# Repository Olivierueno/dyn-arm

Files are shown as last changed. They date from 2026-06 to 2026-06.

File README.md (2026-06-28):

# dyn-arm

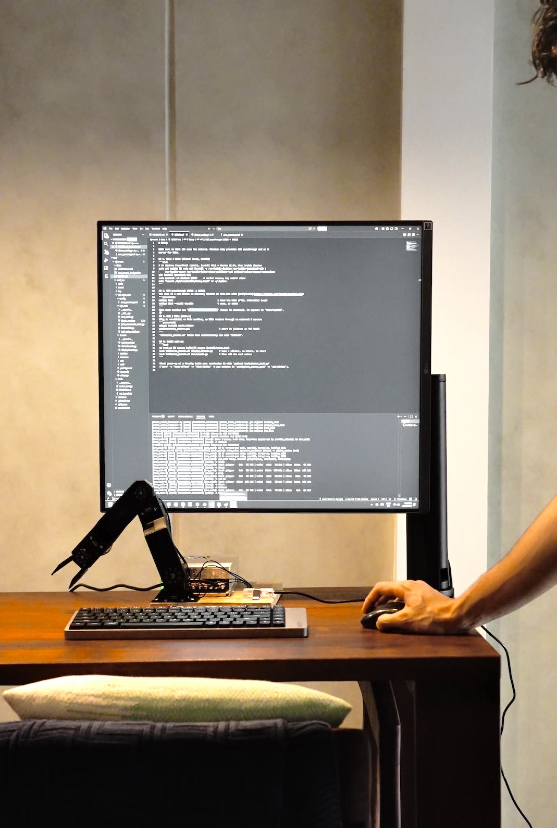
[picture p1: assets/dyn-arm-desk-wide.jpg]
dyn-arm on a desk


A 3-DOF ROS2 robotic arm using Dynamixel servos, 3D-printed structure, a U2D2
USB serial converter, and an RViz digital twin.

## What is included

- ROS2 Humble package for the arm driver, RViz model, and demo.
- STL files in `ros2_ws/src/dyn_arm/meshes/`.
- Motor setup tools in `tools/motor_tool.py`.
- Windows/WSL helpers for U2D2 passthrough and RViz display.
- Safety layers: joint limits, firmware limits, virtual floor, torque caps, and
  watchdog home fallback.

## Hardware

| Qty | Part |
| --- | --- |
| 2 | Dynamixel XM430-W210-R |
| 1 | Dynamixel XM540-W270-R |
| 1 | U2D2 USB serial converter |
| 1 | USB-C cable |
| 1 | 12 V 30 A power supply |
| 1 | Wooden platform |
| 1 | 3D printer |
| 8 | M3 x 10 mm bolts |
| 16 | M3 x 6 mm bolts |
| 8 | M2.5 x 10 mm bolts |
| 8 | M2.5 x 8 mm bolts |

Printed parts are in `ros2_ws/src/dyn_arm/meshes/`. PLA at 50% infill worked
for this build.

## Setup

Install ROS2 Humble on Ubuntu 22.04, then install the project dependencies:

```bash
sudo apt update
sudo apt install -y \
  ros-humble-desktop \
  ros-humble-dynamixel-sdk \
  ros-humble-xacro \
  ros-humble-joint-state-publisher-gui \
  python3-colcon-common-extensions

pip install dynamixel-sdk
sudo usermod -aG dialout $USER
```

Build the workspace:

```bash
cd ros2_ws
colcon build
source install/setup.bash
cd ..
```

For WSL2 USB/RViz notes and first motor setup, see [docs/SETUP.md](docs/SETUP.md).

## Commissioning

With the U2D2 attached as `/dev/ttyUSB0` and the 12 V motor supply on:

```bash
python3 tools/motor_tool.py scan
python3 tools/motor_tool.py zero
python3 tools/motor_tool.py find-limits
```

Copy the measured joint limits into
`ros2_ws/src/dyn_arm/config/arm_params.yaml`, then write them to the motors:

```bash
python3 tools/motor_tool.py set-limits
```

The config arrays are ordered `[gripper, wrist, elbow]`.

## Run

Digital twin only:

```bash
bash tools/ros_launch.sh display.launch.py
```

Real arm with RViz sliders:

```bash
bash tools/ros_launch.sh arm.launch.py
```

Scripted demo:

```bash
bash tools/ros_launch.sh demo.launch.py
```

## More photos

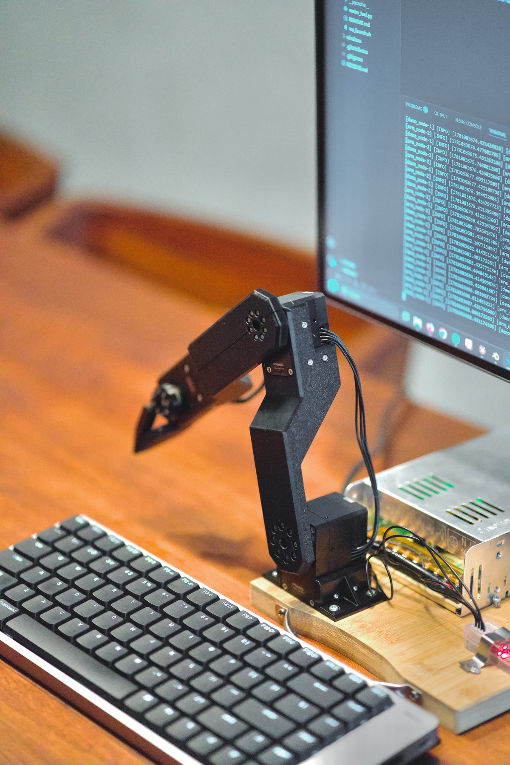
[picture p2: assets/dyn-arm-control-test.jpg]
dyn-arm closeup


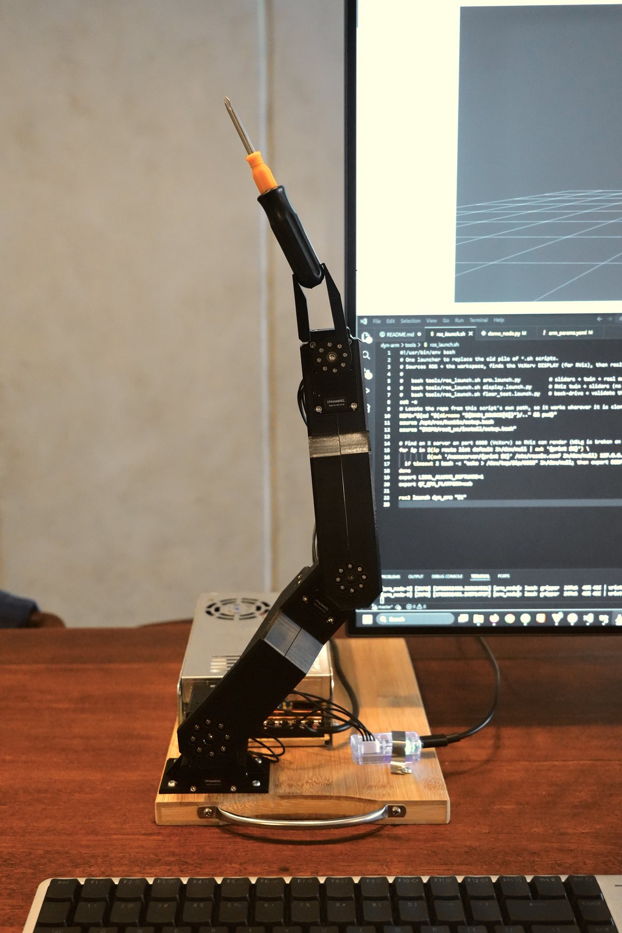
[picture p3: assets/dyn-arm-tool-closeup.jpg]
dyn-arm tool pose


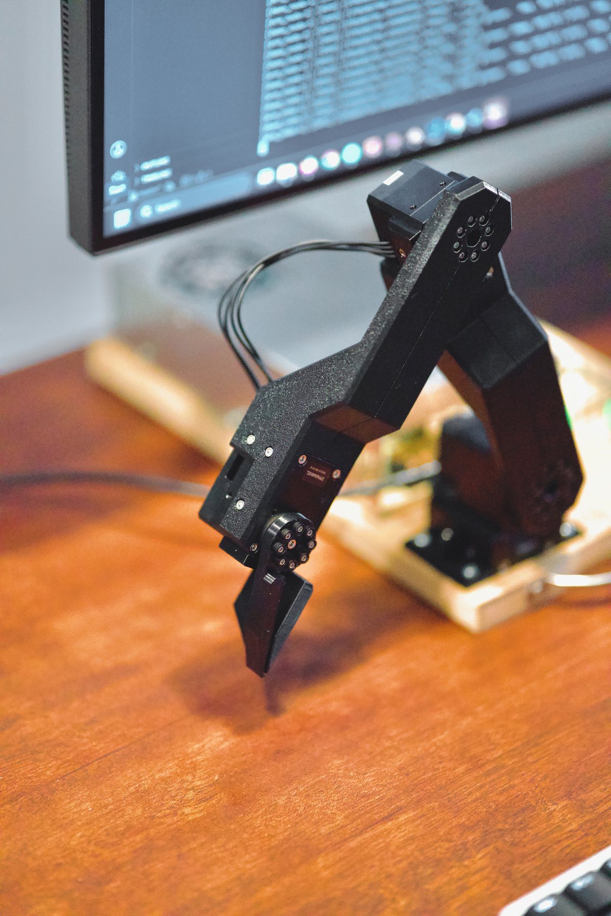
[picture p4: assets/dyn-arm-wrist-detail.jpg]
dyn-arm wrist detail


## Docs

- [Setup guide](docs/SETUP.md)
- [Architecture notes](docs/architecture.md)
- [Torque budget](docs/arm_torque_budget.xlsx)
- [Motor tool reference](tools/README.md)

## License

MIT. See [LICENSE](LICENSE).

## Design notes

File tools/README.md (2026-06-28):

# Tools

Two helpers, both run in WSL.

### `motor_tool.py` - direct-to-motor utilities (not a ROS node)
One CLI for every low-level motor task. U2D2 attached, 12 V on:
```bash
python3 tools/motor_tool.py scan                 # find motors across baud rates
python3 tools/motor_tool.py read                 # pos / goal / torque / error per motor
python3 tools/motor_tool.py zero                 # center all motors (2048) and hold, for assembly
python3 tools/motor_tool.py home-offset 1 2048   # calibrate a joint zero in firmware
python3 tools/motor_tool.py find-limits          # back-drive by hand, capture min/max ticks
python3 tools/motor_tool.py teach                # pose the arm by hand, record demo poses
python3 tools/motor_tool.py set-limits           # burn config lo/hi into motor EEPROM
```
Commissioning order: `zero` -> `home-offset` (if a horn is clocked off) -> `find-limits` ->
copy the numbers into `ros2_ws/src/dyn_arm/config/arm_params.yaml` -> `set-limits`.

### `ros_launch.sh` - the ROS2 launcher
Sources the workspace and sets the RViz display, then launches:
```bash
bash tools/ros_launch.sh arm.launch.py          # sliders + twin + real motors
bash tools/ros_launch.sh demo.launch.py         # hands-free choreography; twin follows
bash tools/ros_launch.sh display.launch.py      # RViz twin only (no motors)
```

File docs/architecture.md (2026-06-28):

# Design notes

## Commanding the arm

Joint targets come from the standard `joint_state_publisher_gui` (one slider per joint),
which publishes `/joint_states` in radians. Two consumers read it:

- `robot_state_publisher` turns it into TF and the RViz **twin**.
- `joint_command_node` converts radians to motor **ticks** and publishes `/goal_positions`,
  which `arm_node` drives the motors from.

So the twin and the real arm are driven from the same source and always agree.
(This project began as a webcam mimic; that input was removed to keep it focused, and it is
recoverable from git history if ever wanted.)

## Coordinates and calibration

Everything is in raw Dynamixel ticks (4096 ticks = one revolution) until the last moment.
`2048` is defined as the **straight-up** pose, where every joint angle is zero. The per-joint
tick<->radian mapping (`CALIB` in `kinematics.py`) is the single place that conversion lives,
used both to drive the motors (radians->ticks) and to draw the twin (ticks->radians).

One servo horn was bolted on ~65 deg off true. Rather than fight the spline, it was corrected
in firmware with the **Homing Offset** register (control-table address 20): the motor adds a
fixed offset to every reported position, so the physical neutral reads as 2048 to all
software above it. It is the digital equivalent of taring a load cell.

## The virtual floor (forward kinematics)

Per-joint limits are a box in joint space; "the gripper must not hit the table" is a diagonal
constraint that couples the elbow and wrist. We compute the gripper-tip height directly:

```
tip_height = elbow_axis_height + L1*cos(elbow) + L2*cos(elbow + wrist)
```

- Angles are measured **from vertical**, so vertical height uses `cos` (a link tilted by
  theta from vertical contributes `L*cos(theta)`). At straight up both cosines are 1, giving
  the maximum tip height (~377 mm); any bend lowers it.
- Both joint signs are **+**, so bending the elbow and wrist the same physical way **adds**
  in `(elbow + wrist)`, matching the real linkage. (A wrong sign here cancels the two angles
  and silently over-estimates the height, a bug found and fixed during bring-up.)

`arm_node` rejects any goal whose predicted tip height is below `floor_margin`, holding the
last safe pose instead. The formula was validated against a tape measure during bring-up by
back-driving the arm (torque off) and comparing the predicted tip height to reality.

## Why current-based holding, not "cut torque on overcurrent"

A tempting failsafe is to watch motor current and disable torque on a spike. That is wrong
for a vertical arm: cutting torque drops it **into** the obstacle. Instead the motors run in
current-based position control (operating mode 5) with a per-joint torque cap, so contact is
a soft current-limited stall that still holds the arm up. This is foldback current limiting,
not an emergency stop.

## Motion smoothing

Motion stays calm via a command **deadband** in the driver (ignore sub-degree goal wobble),
the Dynamixel **profile acceleration/velocity** (trapezoidal ramps instead of instant jerk),
and per-joint **P/D gains**. The light gripper in particular needed high damping (D) and low
stiffness (P) to stop it hunting and chattering at idle.

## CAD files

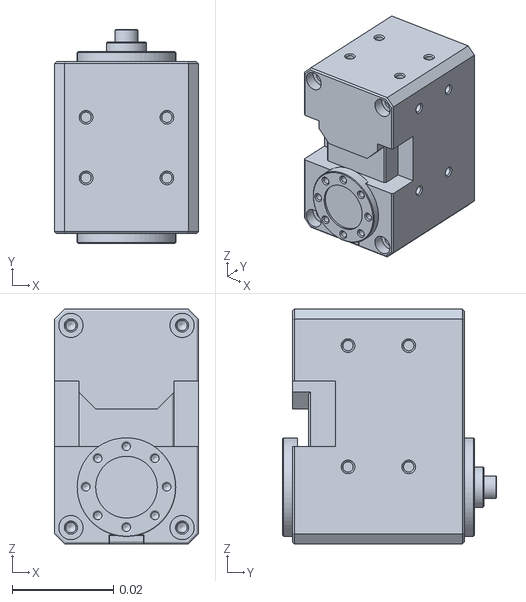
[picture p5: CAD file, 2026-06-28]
ros2_ws/src/dyn_arm/meshes/xm430.stl
0.0285 x 0.0424 x 0.0465

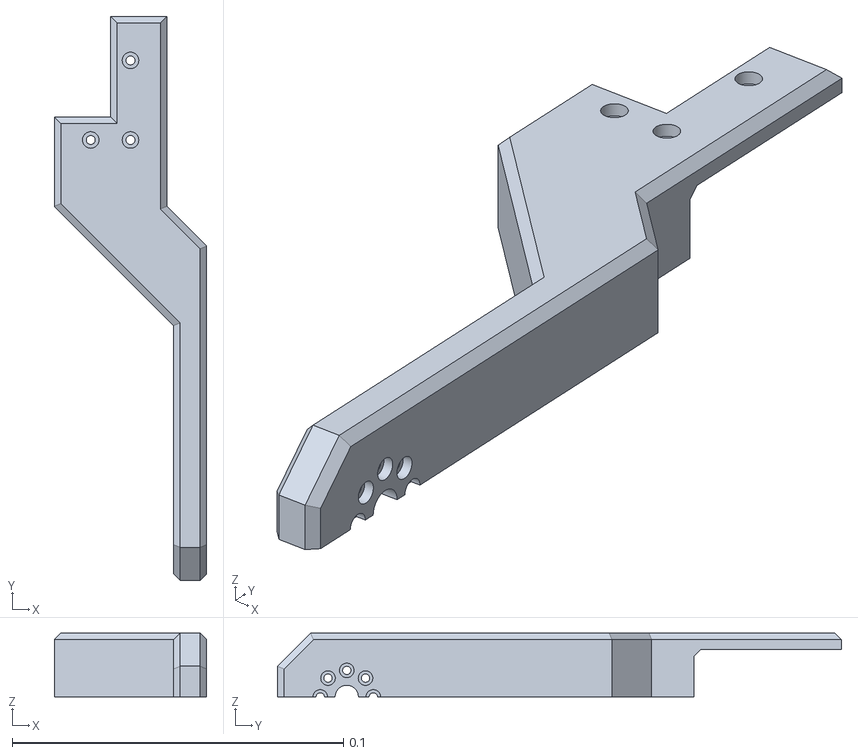
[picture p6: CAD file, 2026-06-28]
ros2_ws/src/dyn_arm/meshes/j2j1_member.stl
0.046 x 0.17 x 0.0192

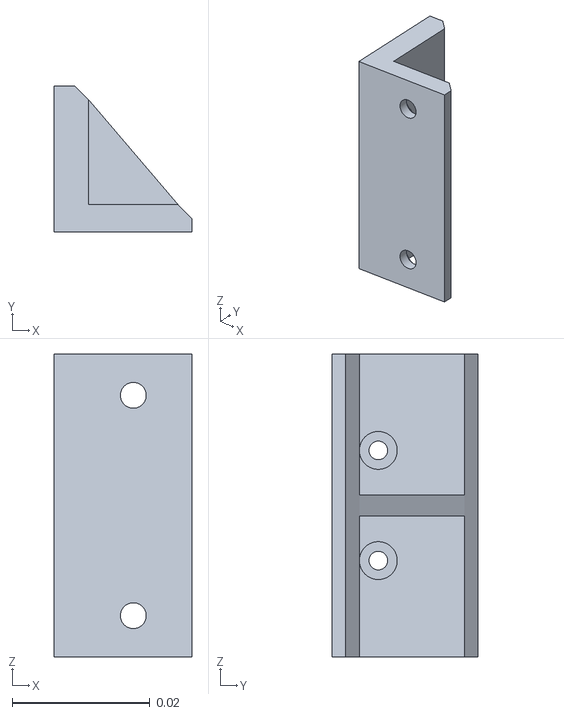
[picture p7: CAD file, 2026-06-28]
ros2_ws/src/dyn_arm/meshes/anchor_bracket.stl
0.02 x 0.0213 x 0.044

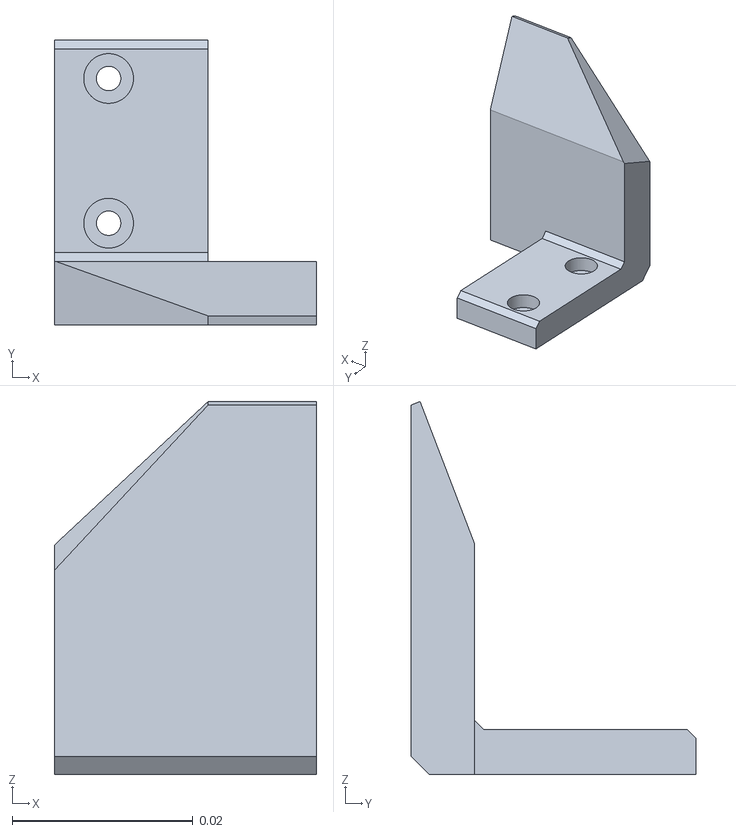
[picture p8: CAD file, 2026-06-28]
ros2_ws/src/dyn_arm/meshes/gripper_base.stl
0.029 x 0.0315 x 0.0412

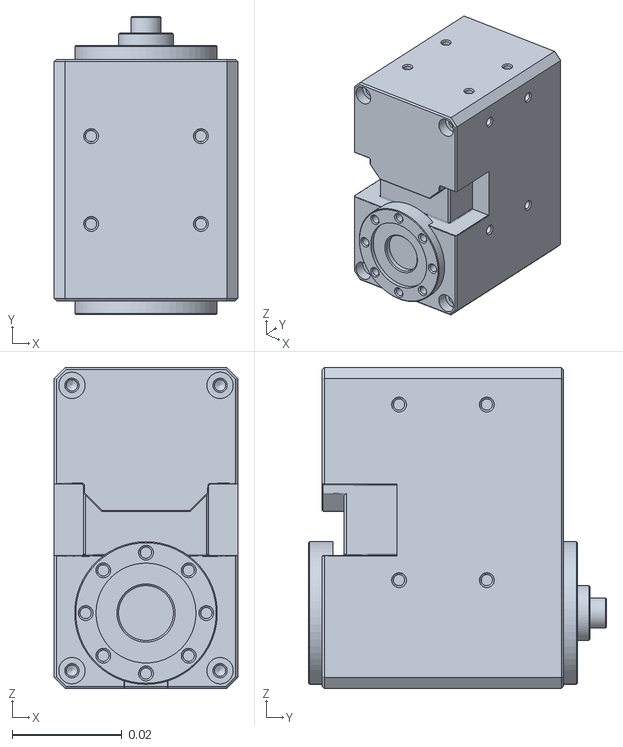
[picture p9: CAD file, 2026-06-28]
ros2_ws/src/dyn_arm/meshes/xm540.stl
0.0335 x 0.0543 x 0.0585

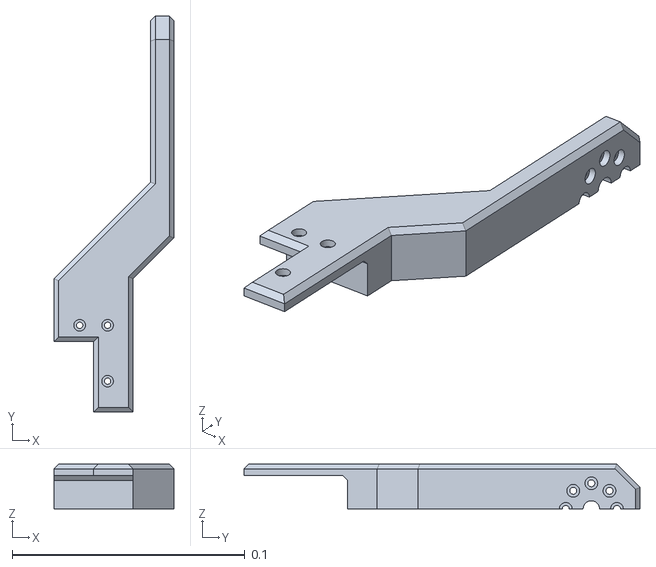
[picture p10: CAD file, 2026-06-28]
ros2_ws/src/dyn_arm/meshes/j3j2_member_mirrored.stl
0.0515 x 0.17 x 0.0192

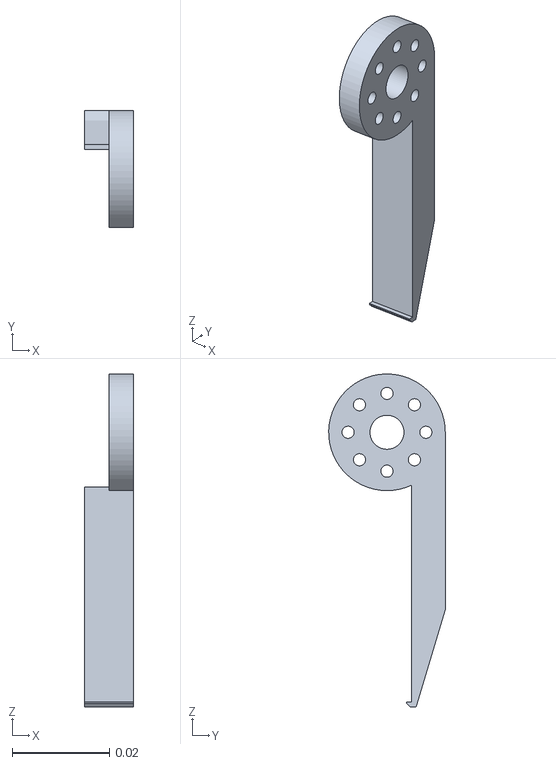
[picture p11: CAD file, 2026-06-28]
ros2_ws/src/dyn_arm/meshes/gripper_actuator.stl
0.01 x 0.024 x 0.0685

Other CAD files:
ros2_ws/src/dyn_arm/meshes/j2j1_member_mirrored.stl
ros2_ws/src/dyn_arm/meshes/j3j2_member.stl

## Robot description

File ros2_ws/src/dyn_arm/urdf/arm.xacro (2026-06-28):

<?xml version="1.0"?>
<!-- xacro: supports variables (${name}) and math, including pi.
     Angles: 180 deg = ${pi}, 90 deg = ${pi/2}. <origin xyz> is in METERS.
     Meshes are referenced by package:// so the model is portable (no absolute paths). -->
<robot name="dyn_arm" xmlns:xacro="http://www.ros.org/wiki/xacro">

  <xacro:property name="meshes" value="package://dyn_arm/meshes"/>
  <xacro:property name="link_len" value="0.14"/>   <!-- axis-to-axis member length, meters -->

  <material name="pla"><color rgba="0.10 0.10 0.11 1"/></material>
  <material name="motor"><color rgba="0.15 0.32 0.60 1"/></material>

  <!-- ============ BASE: anchor bracket + elbow motor ============ -->
  <link name="base_link">
    <visual>
      <origin xyz="0 0.01675 0" rpy="${pi/2} 0 ${pi/2}"/>
      <geometry><mesh filename="${meshes}/anchor_bracket.stl"/></geometry>
      <material name="pla"/>
    </visual>
    <visual>
      <origin xyz="0 -0.01675 0" rpy="${pi/2} 0 -${pi/2}"/>
      <geometry><mesh filename="${meshes}/anchor_bracket.stl"/></geometry>
      <material name="pla"/>
    </visual>
    <visual>
      <origin xyz="0 0 0.04475" rpy="${pi} 0 ${pi/2}"/>             <!-- elbow motor (XM540), flipped 180 -->
      <geometry><mesh filename="${meshes}/xm540.stl"/></geometry>
      <material name="motor"/>
    </visual>
  </link>

  <joint name="elbow" type="revolute">
    <parent link="base_link"/>
    <child link="forearm_link"/>
    <origin xyz="0 0 0.04475" rpy="${pi/2} 0 0"/>
    <axis xyz="1 0 0"/>
    <limit lower="-${pi/2}" upper="${pi/2}" effort="10.6" velocity="3"/>
  </joint>

  <!-- ============ FOREARM: J3J2 member ============ -->
  <link name="forearm_link">
    <visual>
      <origin xyz="0.0245 0 0" rpy="0 0 0"/>
      <geometry><mesh filename="${meshes}/j3j2_member.stl"/></geometry>
      <material name="pla"/>
    </visual>
    <visual>
      <origin xyz="0.0245 0 0" rpy="${pi} 0 0"/>
      <geometry><mesh filename="${meshes}/j3j2_member_mirrored.stl"/></geometry>
      <material name="pla"/>
    </visual>
    <visual>
      <origin xyz="0 0.14 0" rpy="0 ${pi/2} -${pi/2}"/>             <!-- wrist motor (XM430) -->
      <geometry><mesh filename="${meshes}/xm430.stl"/></geometry>
      <material name="motor"/>
    </visual>
  </link>

  <joint name="wrist" type="revolute">
    <parent link="forearm_link"/>
    <child link="hand_link"/>
    <origin xyz="0 ${link_len} 0" rpy="0 0 0"/>
    <axis xyz="1 0 0"/>
    <limit lower="${-3*pi/4}" upper="${3*pi/4}" effort="3" velocity="3"/>
  </joint>

  <!-- ============ HAND: J2J1 member + wrist motor ============ -->
  <link name="hand_link">
    <visual>
      <origin xyz="0.019 0 0" rpy="0 0 0"/>
      <geometry><mesh filename="${meshes}/j2j1_member.stl"/></geometry>
      <material name="pla"/>
    </visual>
    <visual>
      <origin xyz="0.019 0 0" rpy="${pi} 0 0"/>
      <geometry><mesh filename="${meshes}/j2j1_member_mirrored.stl"/></geometry>
      <material name="pla"/>
    </visual>
    <visual>
      <origin xyz="0 0.14 0" rpy="0 ${pi/2} -${pi/2}"/>
      <geometry><mesh filename="${meshes}/xm430.stl"/></geometry>
      <material name="motor"/>
    </visual>
  </link>

  <joint name="gripper_mount" type="fixed">
    <parent link="hand_link"/>
    <child link="gripper_base_link"/>
    <origin xyz="0 ${link_len} 0" rpy="0 0 0"/>
  </joint>

  <!-- ============ GRIPPER BASE (fixed) ============ -->
  <link name="gripper_base_link">
    <visual>
      <origin xyz="0.0085 0.01125 0" rpy="${pi/2} -${pi} ${pi}"/>
      <geometry><mesh filename="${meshes}/gripper_base.stl"/></geometry>
      <material name="pla"/>
    </visual>
  </link>

  <!-- ============ GRIPPER JAW (moves with the pinch) ============ -->
  <joint name="gripper" type="revolute">
    <parent link="gripper_base_link"/>
    <child link="jaw_link"/>
    <origin xyz="0 0 0" rpy="0 0 0"/>
    <axis xyz="1 0 0"/>
    <limit lower="-0.2" upper="0.425" effort="1" velocity="3"/>   <!-- 0 = closed, ~0.7 rad = open -->
  </joint>
  <link name="jaw_link">
    <visual>
      <origin xyz="0.019 0 0" rpy="-${pi/2} 0 ${pi}"/>
      <geometry><mesh filename="${meshes}/gripper_actuator.stl"/></geometry>
      <material name="pla"/>
    </visual>
  </link>

</robot>

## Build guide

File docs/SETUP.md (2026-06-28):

# Setup

This is the short build path for this arm.

## Parts

- 2x Dynamixel XM430-W210-R.
- 1x Dynamixel XM540-W270-R.
- 1x U2D2 USB serial converter with USB-C cable.
- 1x 12 V 30 A power supply.
- Wooden platform.
- Printed parts from `ros2_ws/src/dyn_arm/meshes/`.
- 8x M3 x 10 mm bolts.
- 16x M3 x 6 mm bolts.
- 8x M2.5 x 10 mm bolts.
- 8x M2.5 x 8 mm bolts.

Print the structural STL files in PLA at 50% infill.

## Assembly

1. Mount the XM540 as the main elbow/base motor.
2. Mount the two XM430 motors as wrist and gripper joints.
3. Bolt the printed structure to the wooden platform.
4. Connect all servos on the Dynamixel TTL bus.
5. Connect the bus to the U2D2.
6. Power the servos from the 12 V supply, not USB.

Before torque is enabled, move the arm by hand and check for binding or cable
snags.

## ROS2

Ubuntu 22.04 with ROS2 Humble:

```bash
sudo apt update
sudo apt install -y \
  ros-humble-desktop \
  ros-humble-dynamixel-sdk \
  ros-humble-xacro \
  ros-humble-joint-state-publisher-gui \
  python3-colcon-common-extensions

pip install dynamixel-sdk
sudo usermod -aG dialout $USER
```

Log out and back in after adding `dialout`.

## WSL2 notes

If running from Windows/WSL2, attach the U2D2 with `usbipd-win`. This repo
includes:

```powershell
windows\attach_u2d2.ps1
windows\start_vcxsrv.ps1
```

The U2D2 should appear in Linux as `/dev/ttyUSB0`.

## Build

```bash
cd ros2_ws
colcon build
source install/setup.bash
cd ..
```

## First motor setup

```bash
python3 tools/motor_tool.py scan
python3 tools/motor_tool.py zero
python3 tools/motor_tool.py find-limits
```

Copy the measured limits into `ros2_ws/src/dyn_arm/config/arm_params.yaml`, then:

```bash
python3 tools/motor_tool.py set-limits
```

Use small movements first:

```bash
bash tools/ros_launch.sh display.launch.py
bash tools/ros_launch.sh arm.launch.py
```

Run the demo after slider control behaves correctly:

```bash
bash tools/ros_launch.sh demo.launch.py
```

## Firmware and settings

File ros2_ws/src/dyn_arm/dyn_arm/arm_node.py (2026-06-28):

"""arm_node: the driver for the whole 3-motor bus.

Owns /dev/ttyUSB0 and exposes:
  sub: /goal_positions     std_msgs/Int32MultiArray [gripper, wrist, elbow] ticks (0..4095)
  pub: /present_positions  std_msgs/Int32MultiArray [gripper, wrist, elbow] ticks @ 20 Hz

Safety, in layers (each catches what the one before cannot):
  1. Per-joint soft limits  - clamp every goal to that joint's safe tick range.
  2. Virtual floor (FK)      - reject any elbow+wrist combo that would drive the tip
                               through the table; hold the last safe pose instead.
  3. Current-limited holding - mode 5 caps torque, so contact is a soft stall that still
                               holds the arm up (never goes limp, never crushes).
  4. Watchdog                - if targets stop arriving, ease back to the home pose.

Every tunable lives in config/arm_params.yaml (loaded by the launch file), so the
behaviour can be changed without editing this code.
"""
import time

import rclpy
from rclpy.node import Node
from std_msgs.msg import Int32MultiArray
from dynamixel_sdk import PortHandler, PacketHandler

from dyn_arm.kinematics import tip_height

# --- X-series control table (same for XM430 and XM540) ---
ADDR_OPERATING_MODE       = 11    # 3 = position, 5 = current-based position
ADDR_TORQUE_ENABLE        = 64
ADDR_POSITION_D_GAIN      = 80    # damping (quiets idle hunting)
ADDR_POSITION_P_GAIN      = 84    # stiffness
ADDR_GOAL_CURRENT         = 102   # torque cap in mode 5 (units ~2.69 mA)
ADDR_PROFILE_ACCELERATION = 108   # accel ramp (0 = instant jerk)
ADDR_PROFILE_VELOCITY     = 112   # speed cap
ADDR_GOAL_POSITION        = 116
ADDR_PRESENT_POSITION     = 132
ADDR_PRESENT_CURRENT      = 126   # signed; load/torque proxy (units ~2.69 mA)
ADDR_PRESENT_TEMPERATURE  = 146   # deg C
CURRENT_POSITION_MODE     = 5
CURRENT_UNIT_MA           = 2.69  # mA per Present-Current count


class ArmNode(Node):
    def __init__(self):
        super().__init__("arm_node")

        # ---- parameters (defaults here; overridden by config/arm_params.yaml) ----
        self.declare_parameter("device", "/dev/ttyUSB0")
        self.declare_parameter("baud", 57600)
        self.declare_parameter("profile_velocity", 50)
        self.declare_parameter("profile_acceleration", 10)
        self.declare_parameter("watchdog_timeout", 1.5)
        # floor geometry (meters / ticks)
        self.declare_parameter("elbow_axis_height", 0.04475)
        self.declare_parameter("link1", 0.140)
        self.declare_parameter("link2", 0.192)
        self.declare_parameter("floor_margin", 0.015)
        self.declare_parameter("zero_tick", 2048)
        # per-joint arrays, all in order [gripper, wrist, elbow]
        self.declare_parameter("ids", [1, 2, 3])
        self.declare_parameter("names", ["gripper", "wrist", "elbow"])
        self.declare_parameter("lo", [1903, 456, 920])
        self.declare_parameter("hi", [2316, 3639, 3174])
        self.declare_parameter("goal_current", [200, 300, 500])
        self.declare_parameter("p_gain", [400, 800, 800])
        self.declare_parameter("d_gain", [4500, 1200, 1200])
        self.declare_parameter("deadband", [12, 8, 8])
        self.declare_parameter("home", [2048, 2048, 2048])

        gp = lambda n: self.get_parameter(n).value
        self.device = gp("device")
        self.profile_velocity = gp("profile_velocity")
        self.profile_acceleration = gp("profile_acceleration")
        self.watchdog_timeout = gp("watchdog_timeout")
        self.floor_margin = gp("floor_margin")
        self.geom = dict(elbow_axis_h=gp("elbow_axis_height"), link1=gp("link1"),
                         link2=gp("link2"), zero_tick=gp("zero_tick"))

        ids, names = gp("ids"), gp("names")
        lo, hi, gc = gp("lo"), gp("hi"), gp("goal_current")
        pg, dg, db = gp("p_gain"), gp("d_gain"), gp("deadband")
        self.motors = [dict(id=ids[i], name=names[i], lo=lo[i], hi=hi[i],
                            goal_current=gc[i], p_gain=pg[i], d_gain=dg[i], deadband=db[i])
                       for i in range(len(ids))]
        self.home = {ids[i]: gp("home")[i] for i in range(len(ids))}
        self.elbow_id = ids[names.index("elbow")]
        self.wrist_id = ids[names.index("wrist")]

        # ---- open the bus and set every motor up ----
        self.port = PortHandler(self.device)
        self.packet = PacketHandler(2.0)
        if not self.port.openPort():
            raise RuntimeError(f"Failed to open {self.device}")
        self.port.setBaudRate(gp("baud"))
        for m in self.motors:
            self._setup_motor(m)

        # ---- runtime state ----
        self.safe_elbow, _, _ = self.packet.read4ByteTxRx(self.port, self.elbow_id, ADDR_PRESENT_POSITION)
        self.safe_wrist, _, _ = self.packet.read4ByteTxRx(self.port, self.wrist_id, ADDR_PRESENT_POSITION)
        self.written = {m["id"]: None for m in self.motors}
        self.last_goal_time = time.time()
        self.homed = False

        self.pub = self.create_publisher(Int32MultiArray, "present_positions", 10)
        self.create_subscription(Int32MultiArray, "goal_positions", self.on_goal, 10)
        self.create_timer(0.05, self.on_timer)    # 20 Hz state feedback + watchdog
        self.create_timer(0.33, self.on_status)   # ~3 Hz load + temperature telemetry
        names_str = ", ".join(f'{m["name"]}(id{m["id"]})' for m in self.motors)
        self.get_logger().info(f"arm_node ready. Motors: {names_str}")

    def _setup_motor(self, m):
        i = m["id"]
        self.packet.write1ByteTxRx(self.port, i, ADDR_TORQUE_ENABLE, 0)             # off to change mode
        self.packet.write1ByteTxRx(self.port, i, ADDR_OPERATING_MODE, CURRENT_POSITION_MODE)
        self.packet.write2ByteTxRx(self.port, i, ADDR_POSITION_P_GAIN, m["p_gain"])
        self.packet.write2ByteTxRx(self.port, i, ADDR_POSITION_D_GAIN, m["d_gain"])
        self.packet.write4ByteTxRx(self.port, i, ADDR_PROFILE_ACCELERATION, self.profile_acceleration)
        self.packet.write4ByteTxRx(self.port, i, ADDR_PROFILE_VELOCITY, self.profile_velocity)
        present, comm, err = self.packet.read4ByteTxRx(self.port, i, ADDR_PRESENT_POSITION)
        if comm == 0 and err == 0:
            self.packet.write4ByteTxRx(self.port, i, ADDR_GOAL_POSITION, present)   # no-jump: goal=present
        self.packet.write1ByteTxRx(self.port, i, ADDR_TORQUE_ENABLE, 1)
        self.packet.write2ByteTxRx(self.port, i, ADDR_GOAL_CURRENT, m["goal_current"])
        self.get_logger().info(
            f"id {i}: current-pos mode, cap={m['goal_current']}, torque on, holding {present}")

    def on_goal(self, msg):
        self.last_goal_time = time.time()   # fresh target: pet the watchdog
        self.homed = False

        # 1) per-joint soft-limit clamp
        goals = {}
        for m, pos in zip(self.motors, msg.data):
            goals[m["id"]] = max(m["lo"], min(m["hi"], int(pos)))

        # 2) virtual floor: refuse elbow+wrist combos that would hit the table
        if tip_height(goals[self.elbow_id], goals[self.wrist_id], **self.geom) < self.floor_margin:
            goals[self.elbow_id] = self.safe_elbow
            goals[self.wrist_id] = self.safe_wrist
            self.get_logger().warn("virtual floor: goal would hit the table, holding",
                                   throttle_duration_sec=1.0)
        else:
            self.safe_elbow, self.safe_wrist = goals[self.elbow_id], goals[self.wrist_id]

        # 3) deadband: ignore sub-threshold goal wobble (command noise)
        for m in self.motors:
            g = goals[m["id"]]
            prev = self.written[m["id"]]
            if prev is None or abs(g - prev) >= m["deadband"]:
                self.packet.write4ByteTxRx(self.port, m["id"], ADDR_GOAL_POSITION, g)
                self.written[m["id"]] = g

    def on_timer(self):
        # watchdog: no fresh target for a while -> ease home once
        if not self.homed and time.time() - self.last_goal_time > self.watchdog_timeout:
            self.homed = True
            self.get_logger().warn("watchdog: no targets, easing to home pose")
            for m in self.motors:
                self.packet.write4ByteTxRx(self.port, m["id"], ADDR_GOAL_POSITION, self.home[m["id"]])
                self.written[m["id"]] = self.home[m["id"]]
            self.safe_elbow, self.safe_wrist = self.home[self.elbow_id], self.home[self.wrist_id]

        out = []
        for m in self.motors:
            val, comm, err = self.packet.read4ByteTxRx(self.port, m["id"], ADDR_PRESENT_POSITION)
            out.append(int(val) if comm == 0 and err == 0 else -1)
        self.pub.publish(Int32MultiArray(data=out))

    def on_status(self):
        # Load (present current, signed mA) + temperature per motor. Current is a direct
        # proxy for torque/strain; % is against that joint's goal_current cap.
        parts = []
        for m in self.motors:
            raw, c, e = self.packet.read2ByteTxRx(self.port, m["id"], ADDR_PRESENT_CURRENT)
            signed = (raw - 65536 if raw >= 32768 else raw) if (c == 0 and e == 0) else 0
            ma = abs(int(signed * CURRENT_UNIT_MA))
            temp, tc, te = self.packet.read1ByteTxRx(self.port, m["id"], ADDR_PRESENT_TEMPERATURE)
            pct = int(100 * ma / (m["goal_current"] * CURRENT_UNIT_MA))
            parts.append(f"{m['name']} {ma:>4}mA {pct:>3}% {temp}C")
        self.get_logger().info("load: " + " | ".join(parts), throttle_duration_sec=1.0)


def main():
    rclpy.init()
    node = ArmNode()
    try:
        rclpy.spin(node)
    except KeyboardInterrupt:
        pass
    finally:
        for m in node.motors:
            node.packet.write1ByteTxRx(node.port, m["id"], ADDR_TORQUE_ENABLE, 0)
        node.port.closePort()
        rclpy.shutdown()


if __name__ == "__main__":
    main()

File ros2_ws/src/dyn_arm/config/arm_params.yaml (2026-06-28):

# All tunables for the arm live here. Edit this file, not the node code.
# Per-joint arrays are ALWAYS in the order [gripper, wrist, elbow] (motor ids 1, 2, 3).

arm_node:
  ros__parameters:
    device: /dev/ttyUSB0
    baud: 57600

    # --- motion profile (slow + smooth; raise for snappier) ---
    profile_velocity: 120       # speed cap, units 0.229 rev/min (was 50; raise for faster travel)
    profile_acceleration: 16    # accel ramp, units 214.6 rev/min^2 (lowered 25->16: gentler starts so the heavy elbow doesn't lurch)

    # --- failsafe ---
    watchdog_timeout: 1.5       # seconds with no target before easing to home

    # --- virtual floor geometry (meters / ticks); see kinematics.py ---
    elbow_axis_height: 0.04475  # elbow axis above the wood the gripper hits
    link1: 0.140                # elbow axis -> wrist axis
    link2: 0.192                # wrist axis -> nail tip (0.140 + 0.052)
    floor_margin: 0.015         # tip must stay this far above the wood
    zero_tick: 2048             # straight-up pose

    # --- per-joint [gripper, wrist, elbow] ---
    ids:          [1, 2, 3]
    names:        ['gripper', 'wrist', 'elbow']
    lo:           [1903, 456, 920]      # soft min ticks (measured + margin)
    hi:           [2316, 3639, 3174]    # soft max ticks
    home:         [2048, 2048, 2048]    # parked pose ticks
    goal_current: [200, 300, 500]       # torque cap, units ~2.69 mA
    p_gain:       [400, 800, 650]       # position stiffness (elbow softened 800->650 to reduce inertial overshoot)
    d_gain:       [4500, 1200, 1700]    # position damping (elbow raised 1200->1700 to settle weight oscillation)
    deadband:     [12, 8, 8]            # ticks of goal wobble to ignore at rest (rejects command noise / repeated heartbeats)

# Hands-free choreography (poses live in demo_node.py). The demo sends one goal per
# pose and the MOTOR PROFILE above (profile_velocity / profile_acceleration) does the
# smoothing - so motion speed is tuned there, not here. Only the pose timing lives here.
demo:
  ros__parameters:
    step_period: 2.0    # seconds per pose: the motor profiles there, then holds the remainder
    heartbeat: 5.0      # Hz to re-send the held target so the watchdog stays fed (unchanged target = no motor write)
    loop: true          # repeat forever, or false to run once and hold the last pose

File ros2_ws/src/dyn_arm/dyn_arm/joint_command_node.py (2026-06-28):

"""joint_command_node: /joint_states (radians) -> /goal_positions (ticks).

The standard joint_state_publisher_gui publishes joint angles in radians (the sliders).
This node converts them to motor ticks for arm_node, so dragging a slider moves the real
arm and the RViz twin together. It is the inverse of the tick->radian conversion that
feeds RViz, both share the calibration in kinematics.py.
"""
import rclpy
from rclpy.node import Node
from std_msgs.msg import Int32MultiArray
from sensor_msgs.msg import JointState

from dyn_arm.kinematics import CALIB, rad_to_ticks


class JointCommand(Node):
    def __init__(self):
        super().__init__("joint_command")
        self.pub = self.create_publisher(Int32MultiArray, "goal_positions", 10)
        self.create_subscription(JointState, "joint_states", self.on_joint_states, 10)
        self.get_logger().info("joint_command: /joint_states (rad) -> /goal_positions (ticks)")

    def on_joint_states(self, msg):
        # default every joint to its home tick, then fill in whatever the message carries
        ticks = [CALIB[n]["zero"] for n in ("gripper", "wrist", "elbow")]
        for name, pos in zip(msg.name, msg.position):
            if name in CALIB:
                ticks[CALIB[name]["idx"]] = rad_to_ticks(name, pos)
        self.pub.publish(Int32MultiArray(data=ticks))


def main():
    rclpy.init()
    node = JointCommand()
    try:
        rclpy.spin(node)
    except KeyboardInterrupt:
        pass
    finally:
        rclpy.shutdown()


if __name__ == "__main__":
    main()

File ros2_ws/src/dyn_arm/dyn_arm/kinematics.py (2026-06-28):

"""Shared math: converts between motor ticks, joint angles, and the gripper-tip height.

Single source of truth for both the floor guard (arm_node) and the converters
(joint_command_node, floor_probe_node), so they can never disagree.

Convention: 2048 ticks = the straight-up pose = each joint angle 0 (measured FROM vertical).
Both joint signs are +, so bending the elbow and wrist the same physical way ADDS in
(elbow + wrist), which is what the real linkage does.
"""
import math

RAD_PER_TICK = 2 * math.pi / 4096   # 4096 ticks = one full revolution


# ---------------------------------------------------------------------------
# Forward kinematics: the virtual floor
# ---------------------------------------------------------------------------
def joint_angles(elbow_tick, wrist_tick, zero_tick=2048):
    """Elbow and wrist angles in radians from the straight-up zero."""
    e = (elbow_tick - zero_tick) * RAD_PER_TICK
    w = (wrist_tick - zero_tick) * RAD_PER_TICK
    return e, w


def tip_height(elbow_tick, wrist_tick,
               elbow_axis_h=0.04475, link1=0.140, link2=0.192, zero_tick=2048):
    """Gripper-tip height above the mounting surface (m):

        height = elbow_axis_height + L1*cos(elbow) + L2*cos(elbow + wrist)

    Pure cosine because both joints only ever lower the tip from straight up, so the
    maximum (~377 mm) is at the straight-up pose.
    """
    e, w = joint_angles(elbow_tick, wrist_tick, zero_tick)
    return elbow_axis_h + link1 * math.cos(e) + link2 * math.cos(e + w)


# ---------------------------------------------------------------------------
# Joint calibration: tick <-> radian per joint (for RViz <-> motors)
# ---------------------------------------------------------------------------
# idx = position in the [gripper, wrist, elbow] tick array (motor ids 1, 2, 3).
# lo/hi = real measured travel in radians (so the twin shows the true reachable range).
CALIB = {
    "elbow":   {"idx": 2, "zero": 2048, "sign": +1.0, "scale": RAD_PER_TICK, "lo": -1.730, "hi": 1.727},
    "wrist":   {"idx": 1, "zero": 2048, "sign": +1.0, "scale": RAD_PER_TICK, "lo": -2.442, "hi": 2.441},
    "gripper": {"idx": 0, "zero": 2048, "sign": +1.0, "scale": 0.00158,      "lo": -0.20,  "hi": 0.425},
}


def ticks_to_rad(name, tick):
    """One joint's tick value -> clamped radians (for the RViz twin)."""
    c = CALIB[name]
    ang = (tick - c["zero"]) * c["scale"] * c["sign"]
    return max(c["lo"], min(c["hi"], ang))


def rad_to_ticks(name, rad):
    """One joint's radians -> tick value (for commanding the motor)."""
    c = CALIB[name]
    rad = max(c["lo"], min(c["hi"], rad))
    return int(round(c["zero"] + rad / (c["scale"] * c["sign"])))
